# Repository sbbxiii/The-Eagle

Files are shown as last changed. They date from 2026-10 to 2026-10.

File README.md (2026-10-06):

# The Eagle — Custom STM32F405 Autonomous Flight Controller



[]()
[]()


**The Eagle** is a custom, 4-layer high-reliability avionics flight controller (FC) designed around the **STMicroelectronics STM32F405RGT6** microcontroller. Engineered for autonomous Unmanned Aerial Vehicles (UAVs) and high-performance robotics platforms, the board integrates high-bandwidth IMU telemetry, multi-stage power conditioning, blackbox high-rate logging, and deterministic motor signaling into a **40.0 × 40.0 mm** board footprint with a **34.0 × 34.0 mm** mounting hole pattern.

---

## 3D Isometric View

<p align="center">
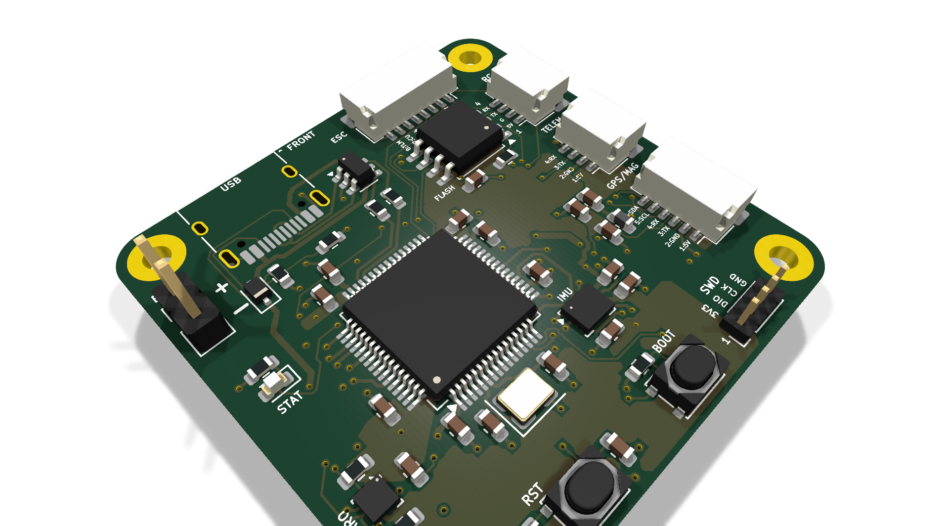
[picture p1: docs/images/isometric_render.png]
The Eagle Isometric Render
  
</p>

---

## Hardware Gallery & Subsystems

| Top View (Components & Silicon) | Bottom View (Power Stages & Silkscreen) |
| :---: | :---: |
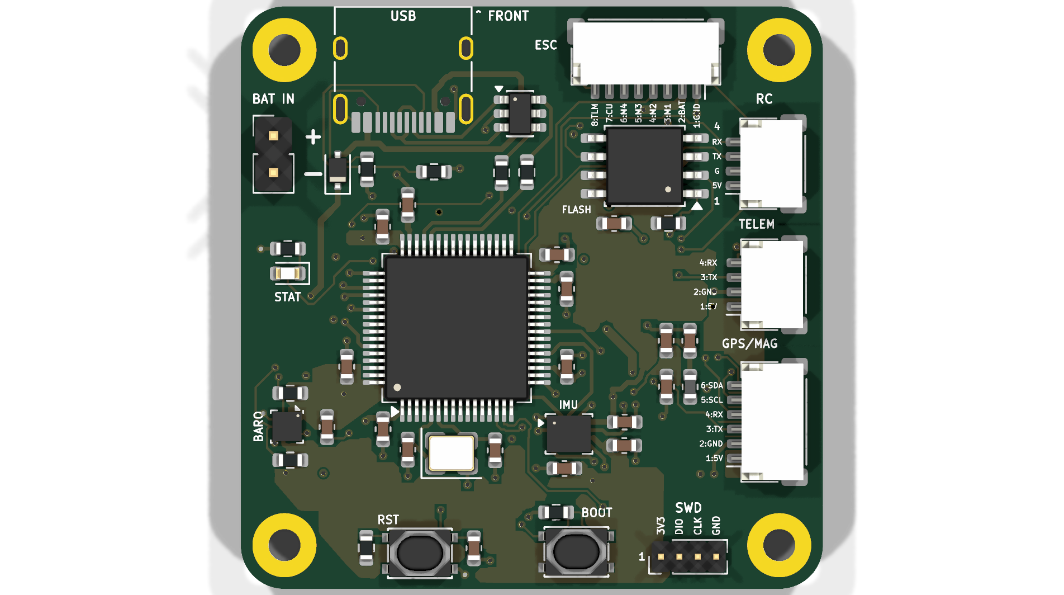
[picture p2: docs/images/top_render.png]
Top View
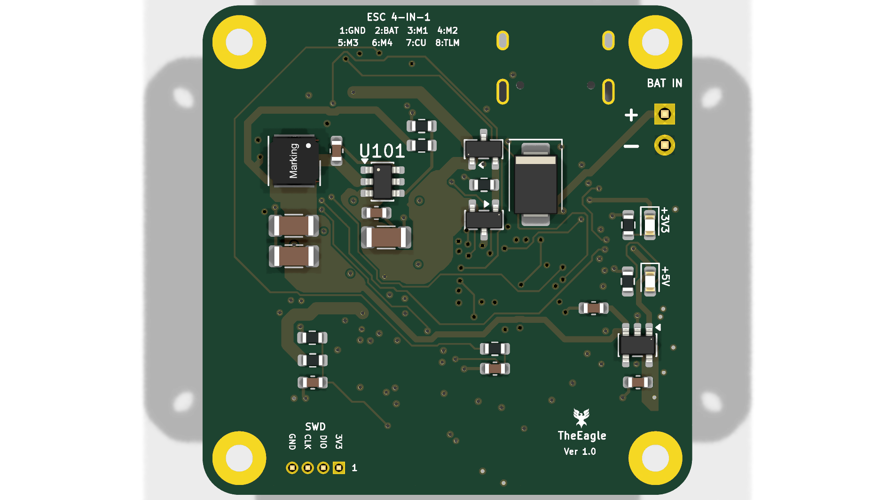
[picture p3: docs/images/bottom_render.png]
Bottom View
|  |  |
| *MCU, IMU, Baro, Flash, SWD, and I/O headers* | *Buck Regulator, LDO, TVS Diode, Reverse-Polarity FET, ESC pads* |

---

## Engineering Highlights & Key Specifications

### 1. Compute & Core Architecture
* **Primary MCU:** STM32F405RGT6 (ARM Cortex-M4 with single-precision FPU, 168 MHz core clock, 1 MB Flash, 192 KB SRAM).
* **Clocking:** External 8.000 MHz crystal oscillator feeding the internal PLL for zero-jitter core timing and USB 48 MHz generation.
* **Programming & Debug:** Onboard 4-pin SWD header (`3V3`, `SWDIO`, `SWCLK`, `GND`) for ST-Link / J-Link debugging and automated CI flashing.
* **Boot Management:** Hardware `BOOT` and `RST` tactile buttons supporting USB DFU system recovery.

### 2. Sensor Suite & Signal Integrity
* **Primary IMU:** **TDK InvenSense ICM-42688-P** 6-axis MEMS gyroscope/accelerometer on a dedicated high-speed **SPI1** bus (up to 20 MHz).
* **Interrupt Routing:** Dedicated hardware `EXTI` Data-Ready (`DRDY`) interrupt line tied directly to the MCU NVIC for deterministic 8 kHz loop timing.
* **Barometric Altimeter:** **Bosch Sensortec BMP390** precision pressure sensor on **I2C1** for sub-meter altitude hold.
* **Blackbox Storage:** **Winbond W25Q128JVSSIQ** (128 Mbit / 16 MB) SPI NOR Flash on **SPI3** for high-rate loop and telemetry logging.
* **Bus Isolation:** SPI and I2C signal traces are referenced directly to an unbroken Layer 2 Ground Plane to suppress crosstalk and high-frequency noise.

### 3. Power Distribution Network (PDN)
* **Battery Input:** 3S–6S LiPo input (9.0V to 26.0V nominal; rated up to 36V transient tolerance).
* **Transient Voltage Suppression (TVS):** Onboard **SMBJ28A** high-energy TVS clamp at the main battery junction to suppress motor inductive voltage spikes.
* **Reverse Polarity Protection:** P-channel MOSFET gate protection preventing accidental battery reverse-connection damage.
* **Synchronous Buck Converter:** Texas Instruments **LMR51430** step-down regulator delivering clean 5.0V @ 3.0A for receivers, telemetry, and peripheral rails.
* **Ultra-Low-Noise Sensor LDO:** Texas Instruments **TLV75733PDBV** (3.3V @ 1.0A) high-PSRR linear regulator exclusively isolating the analog sensors and MCU core.
* **Analog Telemetry:** Low-pass RC filtered 11:1 voltage divider (`VBAT_SENSE`) and ESC analog current input (`CURR_SENSE`).
* **USB Interface:** Micro-USB / USB-C pads protected by ST **USBLC6-2SC6** ultra-low capacitance bidirectional ESD suppressor.

---

## Silicon Registry & Pin Allocation Matrix

| Pin | Function | Peripheral Bus | Alternate Function | Purpose / Notes |
| :--- | :--- | :--- | :--- | :--- |
| **PA0** | `CURR_SENSE` | ADC1 | `ADC1_IN0` | Analog current sensing from ESC |
| **PA1** | `VBAT_SENSE` | ADC1 | `ADC1_IN1` | 11:1 voltage divider battery monitor |
| **PA4** | `IMU_CS` | GPIO | Output | Active-Low SPI Chip Select (ICM-42688-P) |
| **PA5** | `IMU_SCK` | SPI1 | `SPI1_SCK` | High-speed IMU clock (up to 20 MHz) |
| **PA6** | `IMU_MISO` | SPI1 | `SPI1_MISO` | IMU Master In / Slave Out |
| **PA7** | `IMU_MOSI` | SPI1 | `SPI1_MOSI` | IMU Master Out / Slave In |
| **PB0** | `MOTOR_1` | TIM3 | `TIM3_CH3` | Motor 1 output (DShot300/600 / PWM with DMA) |
| **PB1** | `MOTOR_2` | TIM3 | `TIM3_CH4` | Motor 2 output (DShot300/600 / PWM with DMA) |
| **PB4** | `MOTOR_3` | TIM3 | `TIM3_CH1` | Motor 3 output (DShot300/600 / PWM with DMA) |
| **PB5** | `MOTOR_4` | TIM3 | `TIM3_CH2` | Motor 4 output (DShot300/600 / PWM with DMA) |
| **PB6** | `I2C1_SCL` | I2C1 | `I2C1_SCL` | Barometer (BMP390) & External Magnetometer |
| **PB7** | `I2C1_SDA` | I2C1 | `I2C1_SDA` | Barometer (BMP390) & External Magnetometer |
| **PB10** | `UART3_TX` | USART3 | `USART3_TX` | ESC Telemetry / Auxiliary Serial |
| **PB11** | `UART3_RX` | USART3 | `USART3_RX` | ESC Telemetry / Auxiliary Serial |
| **PA9** | `UART1_TX` | USART1 | `USART1_TX` | High-speed Telemetry / Radio Control link |
| **PA10** | `UART1_RX` | USART1 | `USART1_RX` | High-speed Telemetry / Radio Control link |
| **PA2** | `UART2_TX` | USART2 | `USART2_TX` | GPS Receiver (UBX / NMEA protocol) |
| **PA3** | `UART2_RX` | USART2 | `USART2_RX` | GPS Receiver (UBX / NMEA protocol) |
| **PC10** | `FLASH_SCK` | SPI3 | `SPI3_SCK` | Blackbox Flash Clock |
| **PC11** | `FLASH_MISO`| SPI3 | `SPI3_MISO`| Blackbox Flash Data Out |
| **PC12** | `FLASH_MOSI`| SPI3 | `SPI3_MOSI`| Blackbox Flash Data In |
| **PD2** | `FLASH_CS` | GPIO | Output | Blackbox Flash Chip Select (W25Q128) |
| **PA11** | `USB_DM` | USB OTG FS | `OTG_FS_DM` | USB D- with ESD Clamping |
| **PA12** | `USB_DP` | USB OTG FS | `OTG_FS_DP` | USB D+ with ESD Clamping |
| **PA13** | `SWDIO` | SWD | `SWDIO` | Serial Wire Debug Data |
| **PA14** | `SWCLK` | SWD | `SWCLK` | Serial Wire Debug Clock |

---

## PCB Stackup & Fabrication Rules

* **Dimensions:** 40.00 mm × 40.00 mm outer footprint
* **Mounting Pattern:** 34.00 mm × 34.00 mm grid (M2 mounting pads)
* **Layer Count:** 4 Layers (Standard 1.6 mm FR-4 Stackup):
  * **Layer 1 (Top):** Component placement & High-Speed Signal routing
  * **Layer 2 (Inner 1):** Solid Ground Plane (GND) for low return-loop inductance
  * **Layer 3 (Inner 2):** Power Plane split (5.0V / 3.3V power distribution)
  * **Layer 4 (Bottom):** Power Switching Stages, ESC pads, and secondary signal traces
* **Minimum Trace / Space:** 0.15 mm / 0.15 mm (6 mil / 6 mil)
* **Minimum Drill:** 0.3 mm (via size: 0.6 mm outer diameter)
* **Design Rule Check (DRC):** **0 Errors, 0 Unconnected Nets**

---

## Manufacturing & Project Deliverables

All production assets are pre-generated and included in this repository:

* 📄 **Schematic (PDF):** [`schematic/TheEagle_Schematic.pdf`](schematic/TheEagle_Schematic.pdf)
* 📐 **Schematic (SVG):** [`schematic/TheEagle_Schematic.svg`](schematic/TheEagle_Schematic.svg)
* 📦 **Fabrication Gerbers & Drill (ZIP):** [`manufacturing/TheEagle_Gerbers_Rev1.zip`](manufacturing/TheEagle_Gerbers_Rev1.zip)
* 📋 **Bill of Materials (BOM CSV):** [`manufacturing/TheEagle_BOM.csv`](manufacturing/TheEagle_BOM.csv)
* 💻 **KiCad Source Files:** Located in [`hardware/`](hardware/)

---

## Firmware Compatibility

The hardware layout and pin allocation strictly adhere to the STM32 timer and peripheral mapping required by standard flight controller firmware:

1. **ArduPilot (ChibiOS):** Fully compatible via standard ChibiOS `hwdef.dat` board definition.
2. **Betaflight / INAV:** Compatible using STM32F405 target configuration with DShot DMA timer assignment.
3. **Custom Bare-Metal C++ / MATLAB Simulink:** Direct code generation via Embedded Coder / HAL drivers using the onboard SWD debug interface.

---

## How to Open in KiCad

1. Clone this repository:
   ```bash
   git clone https://github.com/sbbxiii/The-Eagle.git
   cd The-Eagle/hardware
   ```
2. Open `AeroHawk_FC.kicad_pro` using **KiCad 8.0 or newer** (tested on KiCad 10.0).
3. View schematics in `Eeschema` or board layout in `Pcbnew`.

---

## Author & License

Designed by **Osakwe**.  
Licensed under the [MIT License](LICENSE).

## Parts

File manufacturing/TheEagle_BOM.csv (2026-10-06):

Refs | Value | Footprint | Qty | DNP
C101 | 10uF 50V | Capacitor_SMD:C_1206_3216Metric | 1
C102 | 0.1uF 50V | Capacitor_SMD:C_0603_1608Metric | 1
C103 | 0.1uF 50V | Capacitor_SMD:C_0603_1608Metric | 1
C104 | 22uF 16V | Capacitor_SMD:C_1206_3216Metric | 1
C105 | 22uF 16V | Capacitor_SMD:C_1206_3216Metric | 1
C106 | 1uF 10V | Capacitor_SMD:C_0603_1608Metric | 1
C107 | 2.2uF 10V | Capacitor_SMD:C_0603_1608Metric | 1
C108 | 100nF | Capacitor_SMD:C_0603_1608Metric | 1
C109 | 100nF | Capacitor_SMD:C_0603_1608Metric | 1
C201 | 100nF | Capacitor_SMD:C_0603_1608Metric | 1
C202 | 100nF | Capacitor_SMD:C_0603_1608Metric | 1
C203 | 100nF | Capacitor_SMD:C_0603_1608Metric | 1
C204 | 100nF | Capacitor_SMD:C_0603_1608Metric | 1
C205 | 4.7uF 10V | Capacitor_SMD:C_0603_1608Metric | 1
C206 | 1uF 10V | Capacitor_SMD:C_0603_1608Metric | 1
C207 | 100nF | Capacitor_SMD:C_0603_1608Metric | 1
C208 | 2.2uF 16V | Capacitor_SMD:C_0603_1608Metric | 1
C209 | 2.2uF 16V | Capacitor_SMD:C_0603_1608Metric | 1
C210 | 33pF C0G | Capacitor_SMD:C_0603_1608Metric | 1
C211 | 33pF C0G | Capacitor_SMD:C_0603_1608Metric | 1
C212 | 100nF | Capacitor_SMD:C_0603_1608Metric | 1
C213 | 1uF 10V | Capacitor_SMD:C_0603_1608Metric | 1
C301 | 100nF | Capacitor_SMD:C_0603_1608Metric | 1
C302 | 1uF 10V | Capacitor_SMD:C_0603_1608Metric | 1
C303 | 100nF | Capacitor_SMD:C_0603_1608Metric | 1
C304 | 100nF | Capacitor_SMD:C_0603_1608Metric | 1
C305 | 100nF | Capacitor_SMD:C_0603_1608Metric | 1
D101 | SMBJ28CA | Diode_SMD:D_SMB | 1
D102 | BZX84C12 | Package_TO_SOT_SMD:SOT-23 | 1
D103 | Green LED | LED_SMD:LED_0603_1608Metric | 1
D104 | Blue LED | LED_SMD:LED_0603_1608Metric | 1
D401 | PMEG3020EJ | Diode_SMD:D_SOD-323F | 1
D403 | Red LED | LED_SMD:LED_0603_1608Metric | 1
FB201 | Ferrite Bead (600Ω) | Inductor_SMD:L_0603_1608Metric | 1
J101 | BAT_IN | Connector_PinHeader_2.54mm:PinHeader_1x02_P2.54mm_Vertical | 1
J201 | SWD_DEBUG | Connector_PinHeader_1.27mm:PinHeader_1x04_P1.27mm_Vertical | 1
J401 | USB_C | Connector_USB:USB_C_Receptacle_HRO_TYPE-C-31-M-12 | 1
J402 | ESC_4IN1 | Connector_JST:JST_SH_SM08B-SRSS-TB_1x08-1MP_P1.00mm_Horizontal | 1
J403 | GPS_MAG | Connector_JST:JST_SH_SM06B-SRSS-TB_1x06-1MP_P1.00mm_Horizontal | 1
J404 | TELEM_GCS | Connector_JST:JST_SH_SM04B-SRSS-TB_1x04-1MP_P1.00mm_Horizontal | 1
J405 | RC_RECEIVER | Connector_JST:JST_SH_SM04B-SRSS-TB_1x04-1MP_P1.00mm_Horizontal | 1
L101 | 10uH | Inductor_SMD_Wurth:L_Wurth_WE-LQSH-4020 | 1
Q101 | Si2319CDS | Package_TO_SOT_SMD:SOT-23 | 1
R101 | 100k | Resistor_SMD:R_0603_1608Metric | 1
R102 | 100k 1% | Resistor_SMD:R_0603_1608Metric | 1
R103 | 13.3k 1% | Resistor_SMD:R_0603_1608Metric | 1
R104 | 10k 0.1% | Resistor_SMD:R_0603_1608Metric | 1
R105 | 1k 0.1% | Resistor_SMD:R_0603_1608Metric | 1
R106 | 1k | Resistor_SMD:R_0603_1608Metric | 1
R107 | 1k | Resistor_SMD:R_0603_1608Metric | 1
R108 | 470R | Resistor_SMD:R_0603_1608Metric | 1
R202 | 10k | Resistor_SMD:R_0603_1608Metric | 1
R203 | 10k | Resistor_SMD:R_0603_1608Metric | 1
R301 | 2.2k | Resistor_SMD:R_0603_1608Metric | 1
R302 | 2.2k | Resistor_SMD:R_0603_1608Metric | 1
R303 | 10k | Resistor_SMD:R_0603_1608Metric | 1
R401 | 5.1k 1% | Resistor_SMD:R_0603_1608Metric | 1
R402 | 5.1k 1% | Resistor_SMD:R_0603_1608Metric | 1
R403 | 22R | Resistor_SMD:R_0603_1608Metric | 1
R404 | 22R | Resistor_SMD:R_0603_1608Metric | 1
R407 | 1k | Resistor_SMD:R_0603_1608Metric | 1
SW201 | Pushbutton (NRST) | Button_Switch_SMD:SW_Push_SPST_NO_PTS810 | 1
SW202 | Pushbutton (BOOT0) | Button_Switch_SMD:SW_Push_SPST_NO_PTS810 | 1
U101 | LMR51430 | Package_TO_SOT_SMD:SOT-23-6 | 1
U102 | TLV75733PDBV | Package_TO_SOT_SMD:SOT-23-5 | 1
U201 | STM32F405RGT6 | Package_QFP:LQFP-64_10x10mm_P0.5mm | 1
U301 | ICM-42688-P | Package_LGA:InvenSense_LGA-14_2.5x3mm_P0.5mm | 1
U302 | BMP390 | Package_LGA:Bosch_LGA-10_2x2mm_P0.5mm | 1
U303 | W25Q128JVSSIQ | Package_SO:SOIC-8_5.23x5.23mm_P1.27mm | 1
U402 | USBLC6-2SC6 | Package_TO_SOT_SMD:SOT-23-6 | 1
Y201 | 8.000MHz | Crystal:Crystal_SMD_3225-4Pin_3.2x2.5mm | 1

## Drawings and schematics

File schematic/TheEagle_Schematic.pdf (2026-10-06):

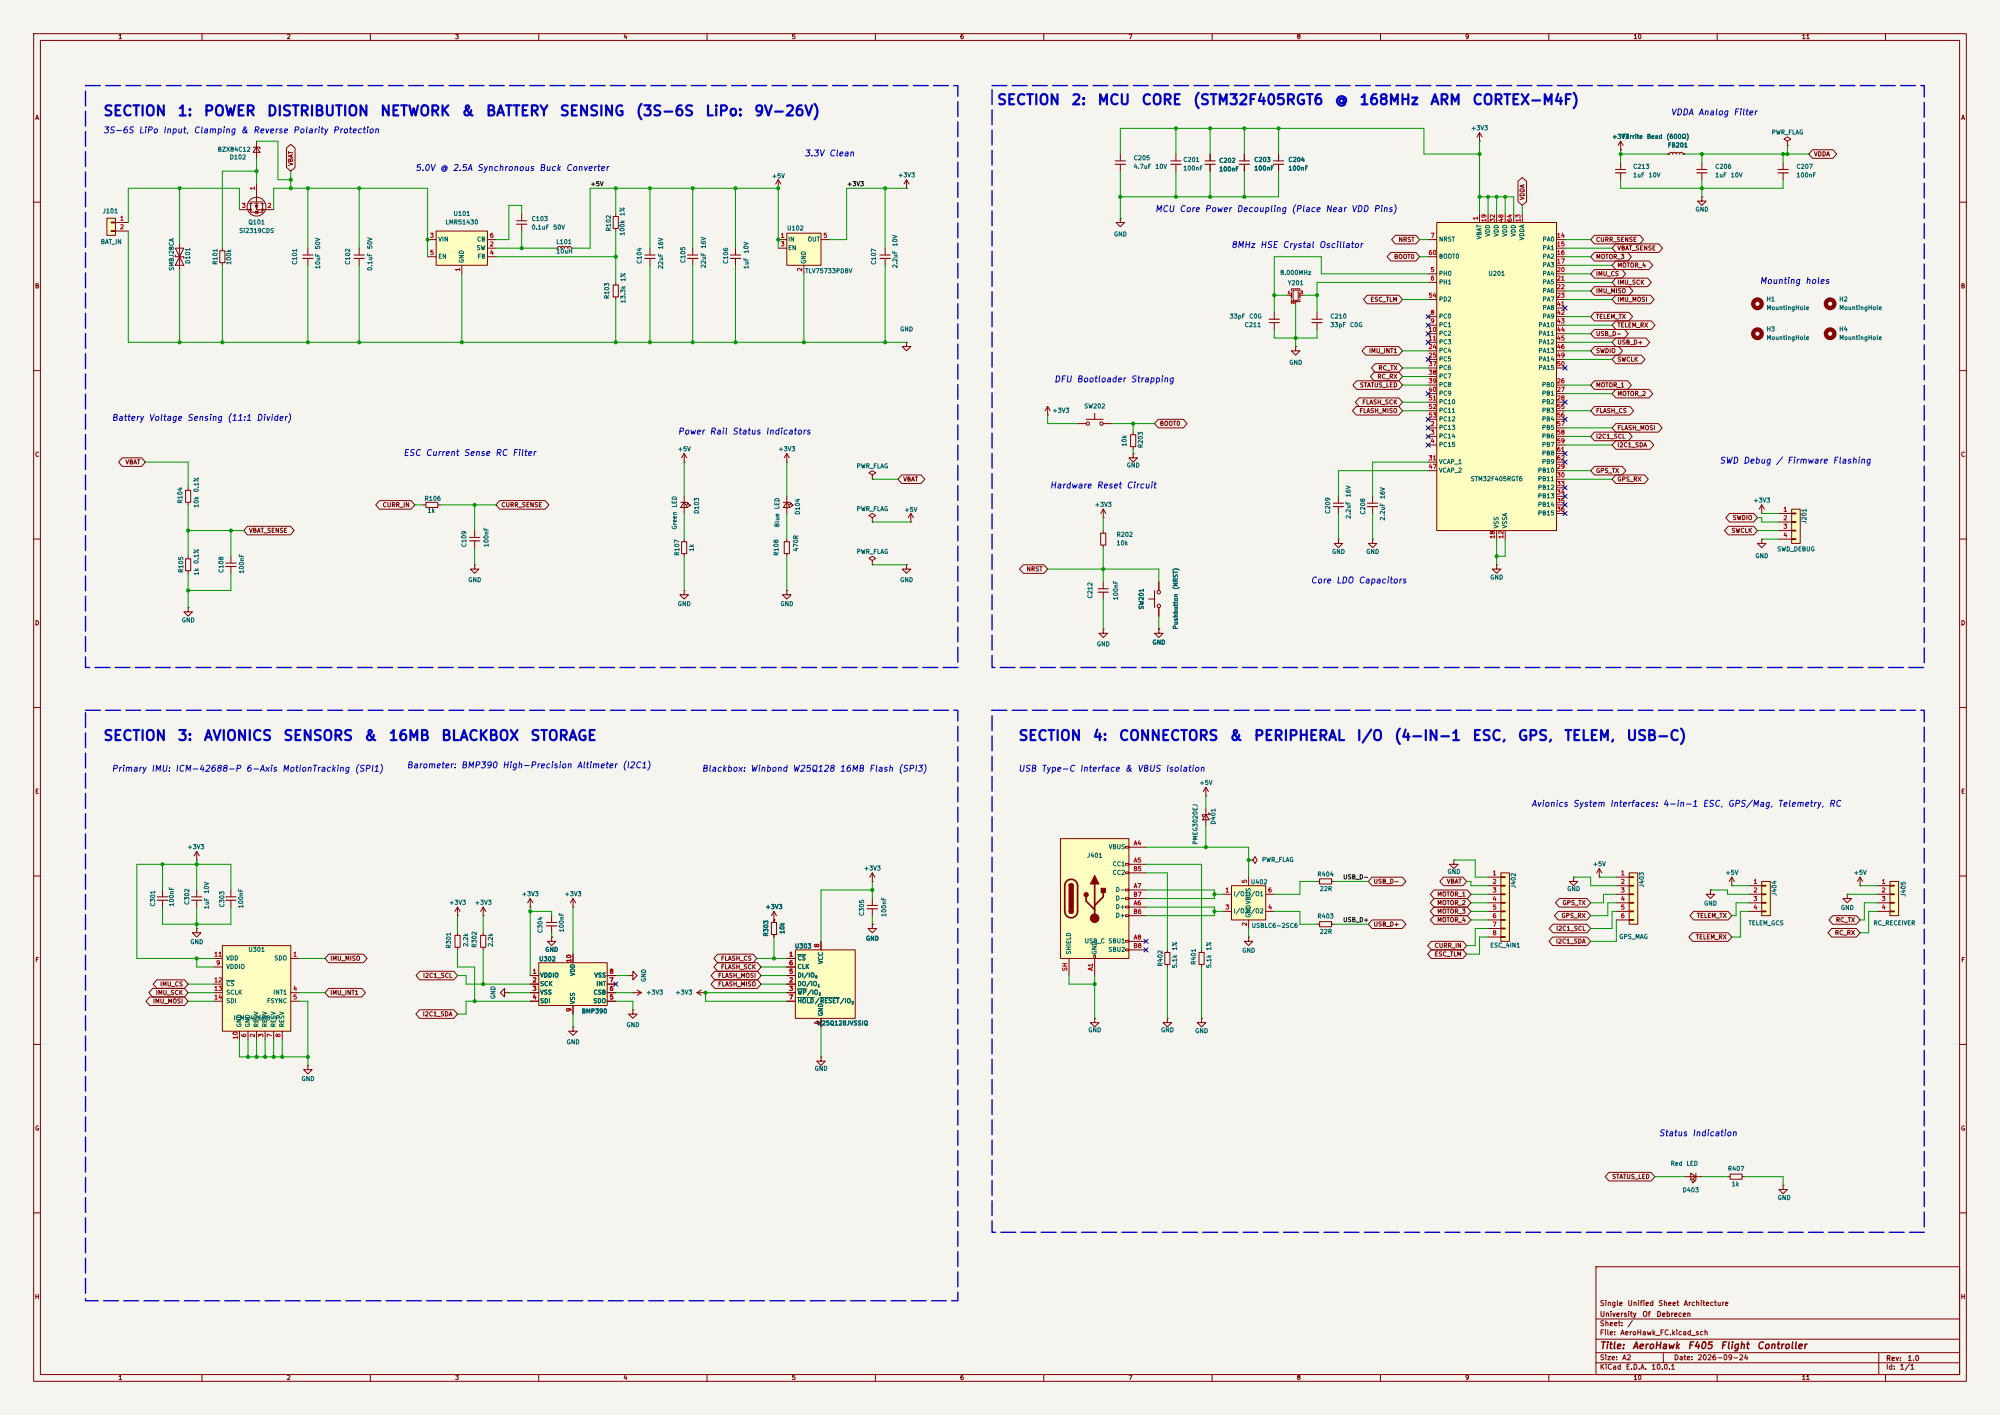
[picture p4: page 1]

SECTION 2: MCU CORE (STM32F405RGT6 @ 168MHz ARM CORTEX-M4F)

SECTION 1: POWER DISTRIBUTION NETWORK & BATTERY SENSING (3S-6S LiPo: 9V-26V)

3S-6S LiPo Input, Clamping & Reverse Polarity Protection

MCU Core Power Decoupling (Place Near VDD Pins)

Battery Voltage Sensing (11:1 Divider)

Power Rail Status Indicators

ESC Current Sense RC Filter

SWD Debug / Firmware Flashing

SECTION 3: AVIONICS SENSORS & 16MB BLACKBOX STORAGE

SECTION 4: CONNECTORS & PERIPHERAL I/O (4-IN-1 ESC, GPS, TELEM, USB-C)

Primary IMU: ICM-42688-P 6-Axis MotionTracking (SPI1)

Avionics System Interfaces: 4-in-1 ESC, GPS/Mag, Telemetry, RC

4 DI/IO0 5 CLK 6 HOLD/RESET/IO3 7 VCC U303 8 GND W25Q128JVSSIQ GND

4 DI/IO0 5 CLK 6 HOLD/RESET/IO3 7 VCC

Single Unified Sheet Architecture
University Of Debrecen
Sheet: /
File: AeroHawk_FC.kicad_sch
Title: AeroHawk F405 Flight Controller

Size: A2 | Rev: 1.0
KiCad E.D.A. 10.0.1 | Id: 1/1

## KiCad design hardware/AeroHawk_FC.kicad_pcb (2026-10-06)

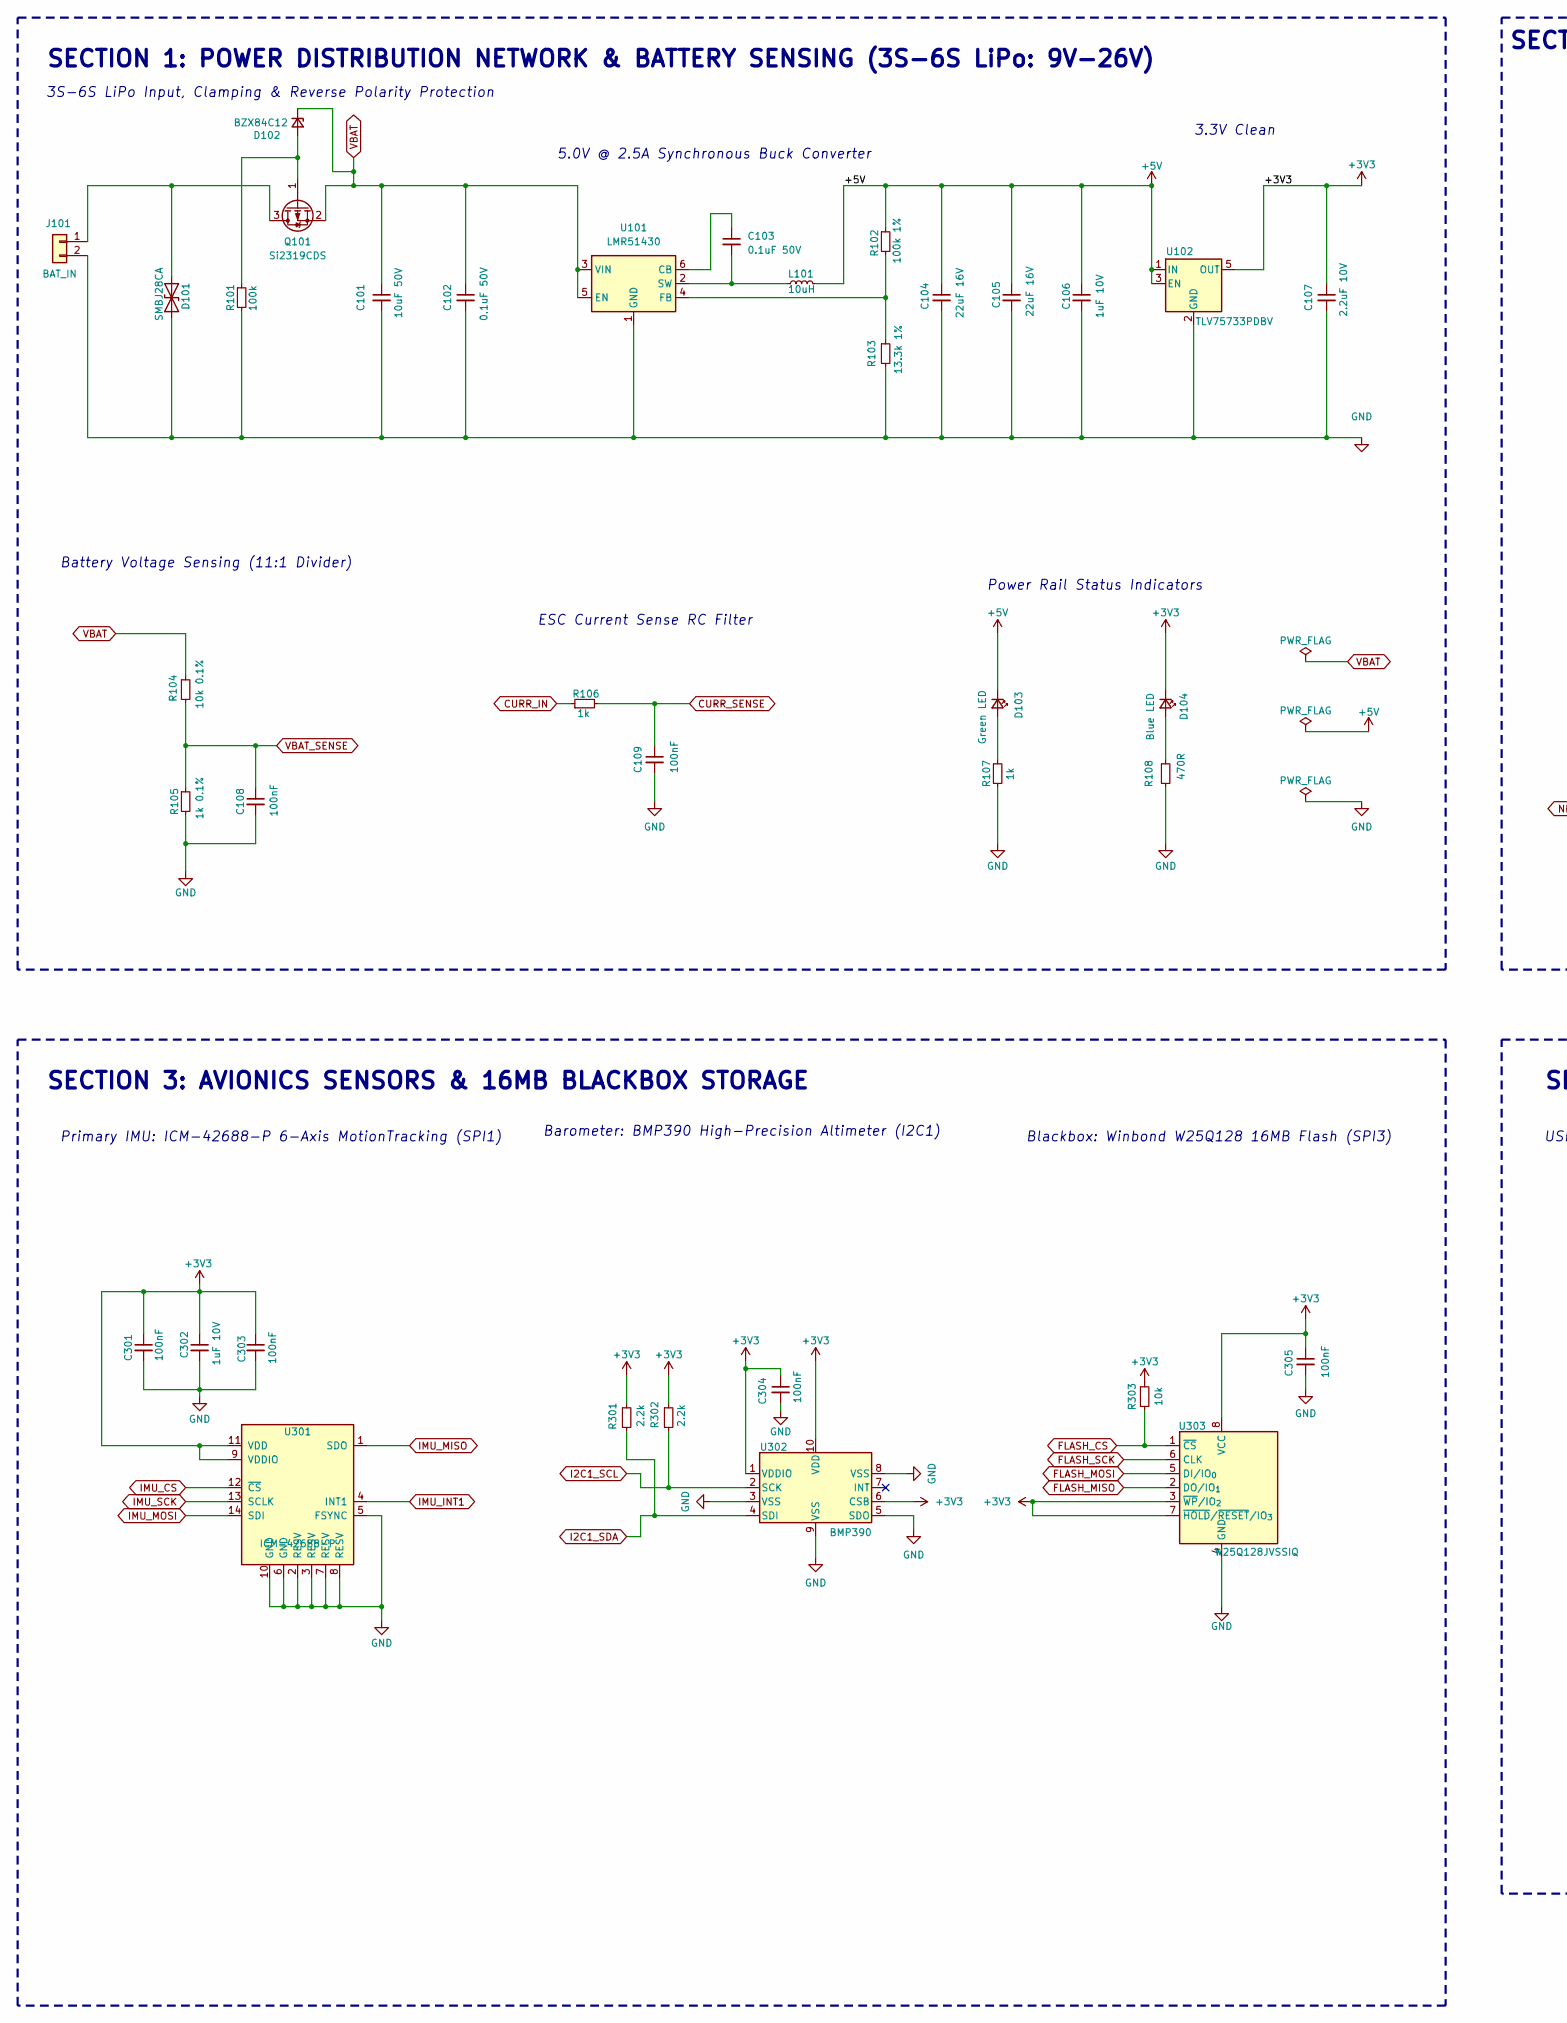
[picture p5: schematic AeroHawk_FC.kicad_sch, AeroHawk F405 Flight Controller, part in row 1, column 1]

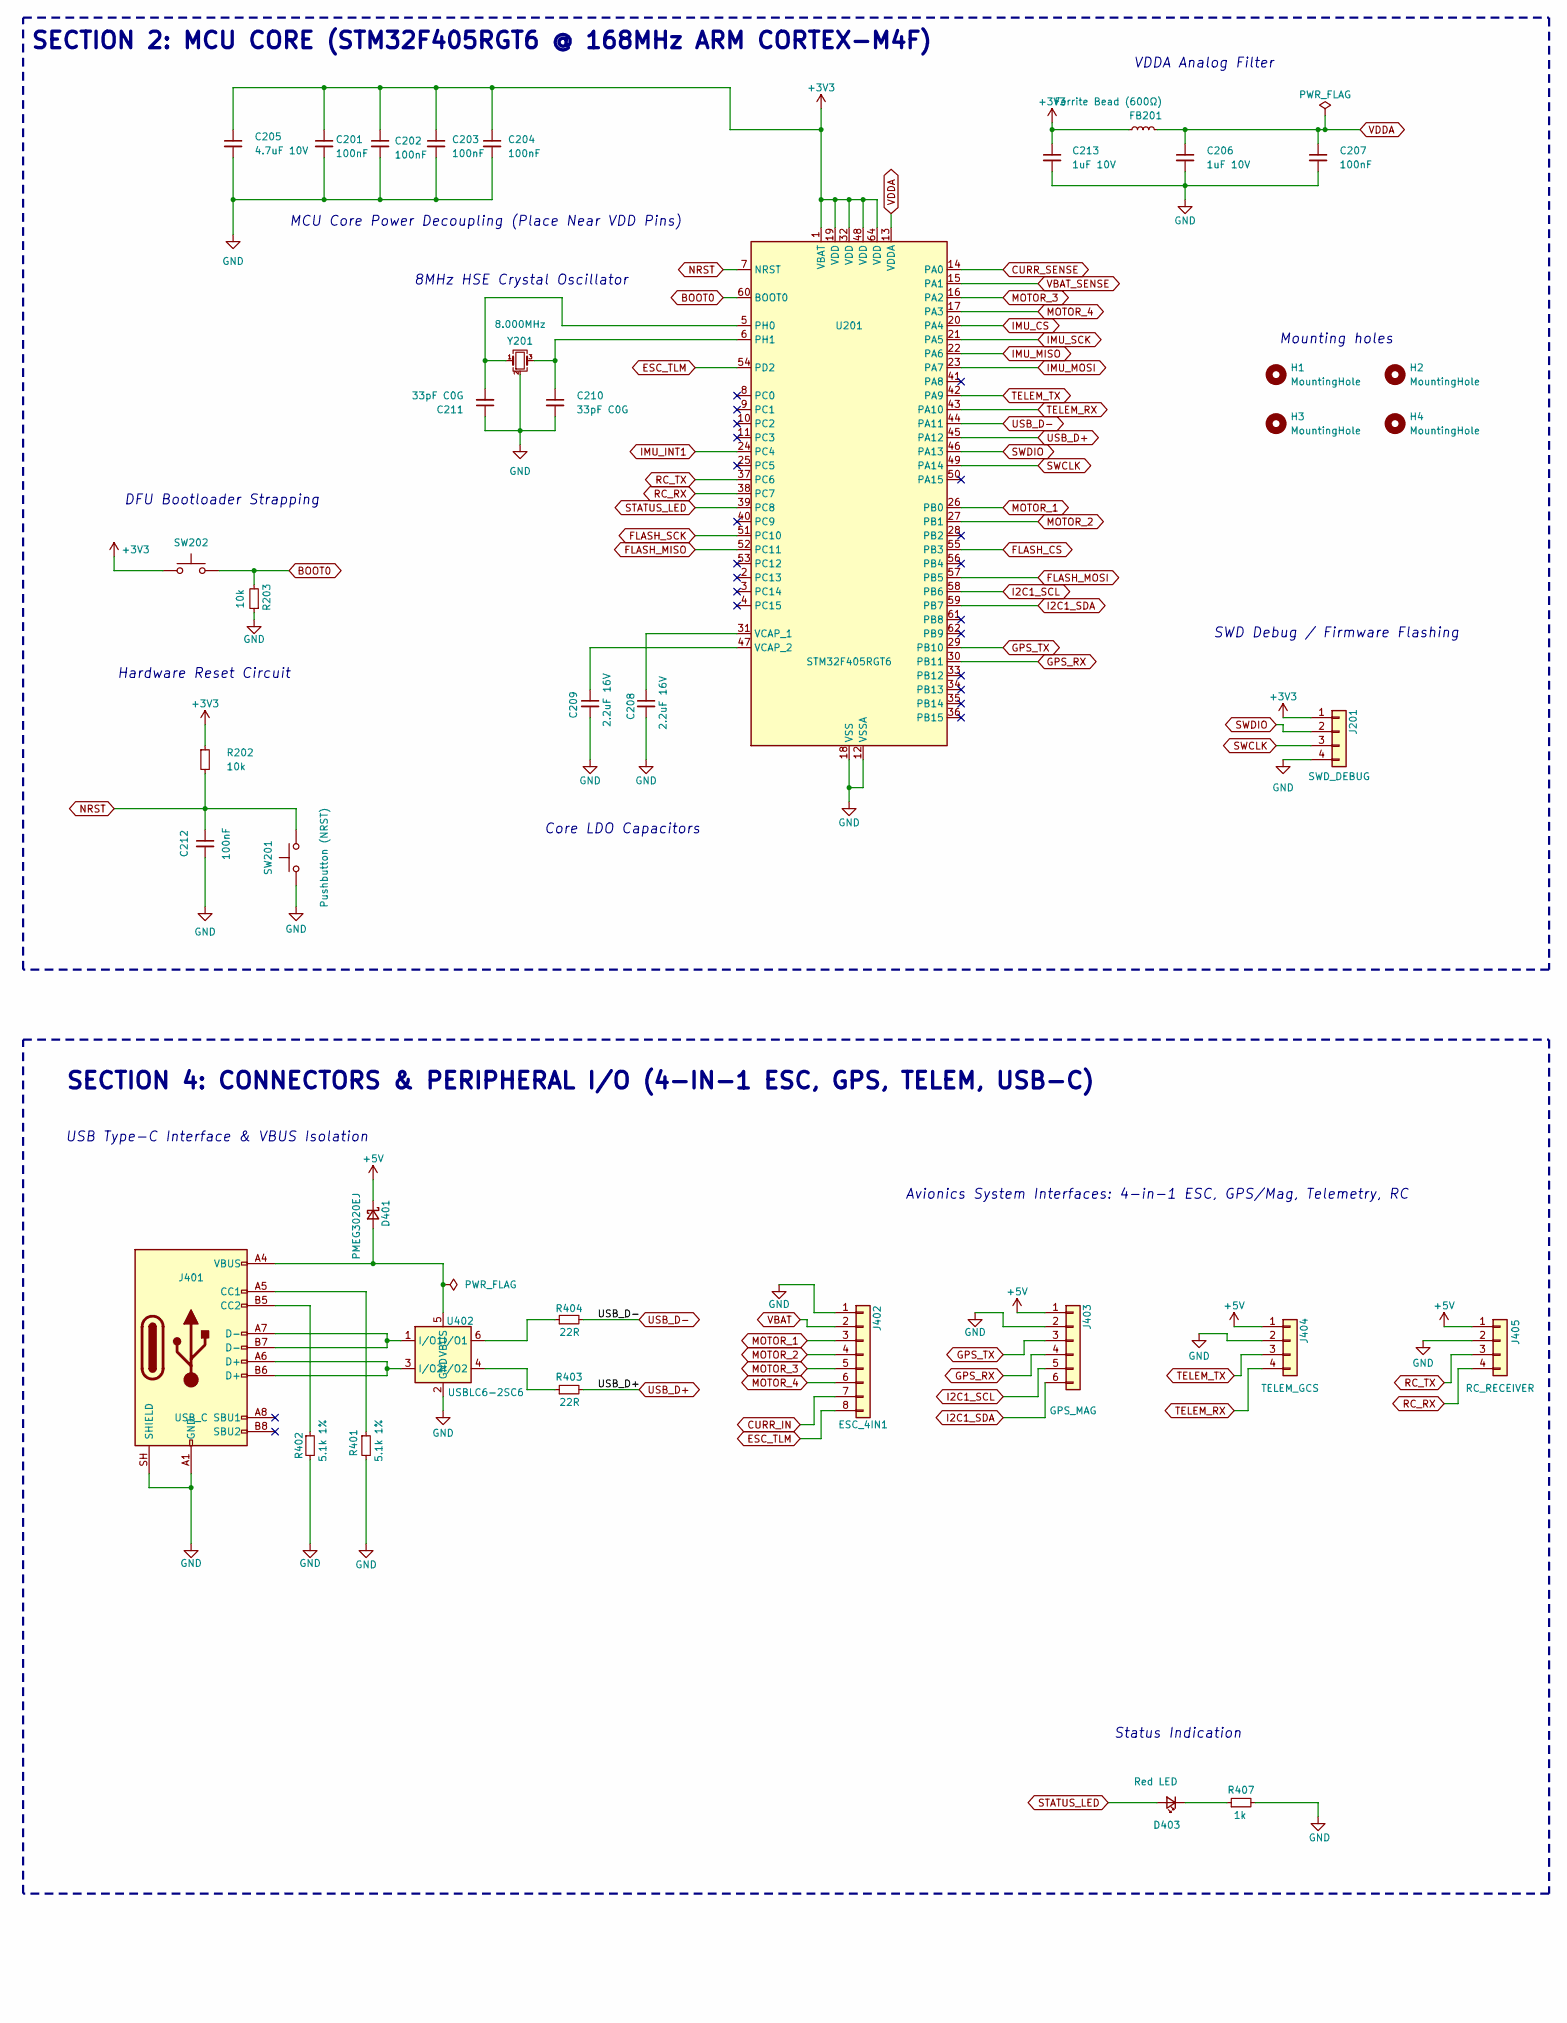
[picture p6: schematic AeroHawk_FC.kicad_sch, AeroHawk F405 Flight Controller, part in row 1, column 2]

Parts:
C101: 10uF 50V; C_1206_3216Metric; MPN CL31B106KBHNNNE
C102, C103: 0.1uF 50V; C_0603_1608Metric; MPN CC0603KRX7R9BB104
C104, C105: 22uF 16V; C_1206_3216Metric; MPN CL21A226MPCLRNC
C106, C206, C213, C302: 1uF 10V; C_0603_1608Metric; MPN CC0603KRX7R7BB105
C107: 2.2uF 10V; C_0603_1608Metric; MPN CC0603KRX7R7BB225
C108, C109, C201, C202, C203, C204, C207, C212, C301, C303, C304, C305: 100nF; C_0603_1608Metric; MPN CC0603KRX7R9BB104
C205: 4.7uF 10V; C_0603_1608Metric; MPN CC0603KRX7R9BB104
C208, C209: 2.2uF 16V; C_0603_1608Metric; MPN CC0603KRX7R7BB225
C210, C211: 33pF C0G; C_0603_1608Metric; MPN CC0603JRNPO9BN180
D101: SMBJ28CA; D_SMB; MPN SMBJ28CA
D102: BZX84C12; SOT-23; MPN BZX84C12
D103: Green LED; LED_0603_1608Metric; MPN 19-217/GHC-YR1S2/3T
D104: Blue LED; LED_0603_1608Metric; MPN 19-217/BHC-AP1Q2/3T
D401: PMEG3020EJ; D_SOD-323F; MPN PMEG3020EJ
D403: Red LED; LED_0603_1608Metric; MPN 19-217/R6C-AL1M2VY/3T
FB201: Ferrite Bead (600Ω); L_0603_1608Metric; MPN BLM18PG121SN1D
H1, H2, H3, H4: MountingHole; MountingHole_2.2mm_M2_Pad
J101: BAT_IN; PinHeader_1x02_P2.54mm_Vertical; MPN 22-23-2021
J201: SWD_DEBUG; PinHeader_1x04_P1.27mm_Vertical; MPN M50-3530442
J401: USB_C; USB_C_Receptacle_HRO_TYPE-C-31-M-12; MPN TYPE-C-31-M-12
J402: ESC_4IN1; JST_SH_SM08B-SRSS-TB_1x08-1MP_P1.00mm_Horizontal; MPN SM08B-SRSS-TB
J403: GPS_MAG; JST_SH_SM06B-SRSS-TB_1x06-1MP_P1.00mm_Horizontal; MPN SM06B-SRSS-TB
J404: TELEM_GCS; JST_SH_SM04B-SRSS-TB_1x04-1MP_P1.00mm_Horizontal; MPN SM04B-SRSS-TB
J405: RC_RECEIVER; JST_SH_SM04B-SRSS-TB_1x04-1MP_P1.00mm_Horizontal; MPN SM04B-SRSS-TB
L101: 10uH; L_Wurth_WE-LQSH-4020; MPN 74405042100
Q101: Si2319CDS; SOT-23; MPN Si2319CDS-T1-GE3
R101: 100k; R_0603_1608Metric; MPN RC0603FR-07100KL
R102: 100k 1%; R_0603_1608Metric; MPN RC0603FR-07100KL
R103: 13.3k 1%; R_0603_1608Metric; MPN RC0603FR-0713K3L
R104: 10k 0.1%; R_0603_1608Metric; MPN RT0603BRD0710KL
R105: 1k 0.1%; R_0603_1608Metric; MPN RT0603BRD071KL
R106, R107, R407: 1k; R_0603_1608Metric; MPN RC0603FR-071KL
R108: 470R; R_0603_1608Metric; MPN RC0603FR-071KL
R202, R203, R303: 10k; R_0603_1608Metric; MPN RC0603FR-0710KL
R301, R302: 2.2k; R_0603_1608Metric; MPN RC0603FR-072K2L
R401, R402: 5.1k 1%; R_0603_1608Metric; MPN RC0603FR-075K1L
R403, R404: 22R; R_0603_1608Metric; MPN RC0603FR-0722RL
SW201: Pushbutton (NRST); SW_Push_SPST_NO_PTS810; MPN PTS810SJM250SMTRLFS
SW202: Pushbutton (BOOT0); SW_Push_SPST_NO_PTS810; MPN PTS810SJM250SMTRLFS
U101: LMR51430; SOT-23-6; MPN LMR51430XDDCR
U102: TLV75733PDBV; SOT-23-5; MPN TLV75733PDBVR
U201: STM32F405RGT6; LQFP-64_10x10mm_P0.5mm; MPN STM32F405RGT6
U301: ICM-42688-P; InvenSense_LGA-14_2.5x3mm_P0.5mm; MPN ICM-42688-P
U302: BMP390; Bosch_LGA-10_2x2mm_P0.5mm; MPN BMP390
U303: W25Q128JVSSIQ; SOIC-8_5.23x5.23mm_P1.27mm; MPN W25Q128JVSIQ
U402: USBLC6-2SC6; SOT-23-6; MPN USBLC6-2SC6
Y201: 8.000MHz; Crystal_SMD_3225-4Pin_3.2x2.5mm; MPN X32258MSB4SI

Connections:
+3V3: C107.1, C201.1, C202.1, C203.1, C204.1, C205.1, C213.1, C301.1, C302.1, C303.1, C304.1, C305.1, D104.1 (K), FB201.1, J201.1, R202.1, R301.1, R302.1, R303.1, SW202.1, U102.5 (OUT), U201.1 (VBAT), U201.19 (VDD), U201.32 (VDD), U201.48 (VDD), U201.64 (VDD), U301.9 (VDDIO), U301.11 (VDD), U302.1 (VDDIO), U302.6 (CSB), U302.10 (VDD), U303.3 (~WP/IO_{2}), U303.7 (~HOLD/~RESET/IO_{3}), U303.8 (VCC)
BOOT0: R203.2, SW202.2, U201.60 (BOOT0)
CURR_IN: J402.7, R106.1
CURR_SENSE: C109.1, R106.2, U201.14 (PA0)
ESC_TLM: J402.8, U201.54 (PD2)
FLASH_CS: R303.2, U201.55 (PB3), U303.1 (~CS)
FLASH_MISO: U201.52 (PC11), U303.2 (DO/IO_{1})
FLASH_MOSI: U201.57 (PB5), U303.5 (DI/IO_{0})
FLASH_SCK: U201.51 (PC10), U303.6 (CLK)
GPS_RX: J403.4, U201.30 (PB11)
GPS_TX: J403.3, U201.29 (PB10)
I2C1_SCL: J403.5, R302.2, U201.58 (PB6), U302.2 (SCK)
I2C1_SDA: J403.6, R301.2, U201.59 (PB7), U302.4 (SDI)
IMU_CS: U201.20 (PA4), U301.12 (~CS)
IMU_INT1: U201.24 (PC4), U301.4 (INT1)
IMU_MISO: U201.22 (PA6), U301.1 (SDO)
IMU_MOSI: U201.23 (PA7), U301.14 (SDI)
IMU_SCK: U201.21 (PA5), U301.13 (SCLK)
MOTOR_1: J402.3, U201.26 (PB0)
MOTOR_2: J402.4, U201.27 (PB1)
MOTOR_3: J402.5, U201.16 (PA2)
MOTOR_4: J402.6, U201.17 (PA3)
NRST: C212.1, R202.2, SW201.2, U201.7 (NRST)
unnamed: D101.2 (A2), J101.1, Q101.3 (D)
unnamed: D102.2 (A), Q101.1 (G), R101.1
unnamed: D103.2 (A), R107.1
unnamed: D104.2 (A), R108.1
unnamed: D403.1 (K), R407.1
unnamed: J401.A5 (CC1), R401.1
unnamed: J401.B5 (CC2), R402.1
unnamed: J401.A6 (D+), J401.B6 (D+), U402.3 (I/O2)
unnamed: J401.A7 (D-), J401.B7 (D-), U402.1 (I/O1)
unnamed: R403.1, U402.4 (I/O2)
unnamed: R404.1, U402.6 (I/O1)
unnamed: C103.1, U101.6 (CB)
unnamed: R102.2, R103.1, U101.4 (FB)
unnamed: C103.2, L101.1, U101.2 (SW)
unnamed: C211.2, U201.5 (PH0), Y201.1
unnamed: C210.1, U201.6 (PH1), Y201.3
unnamed: C208.1, U201.31 (VCAP_1)
unnamed: C209.1, U201.47 (VCAP_2)
RC_RX: J405.4, U201.38 (PC7)
RC_TX: J405.3, U201.37 (PC6)
STATUS_LED: D403.2 (A), U201.39 (PC8)
SWCLK: J201.3, U201.49 (PA14)
SWDIO: J201.2, U201.46 (PA13)
TELEM_RX: J404.4, U201.43 (PA10)
TELEM_TX: J404.3, U201.42 (PA9)
USB_D+: R403.2, U201.45 (PA12)
USB_D-: R404.2, U201.44 (PA11)
VBAT_SENSE: C108.1, R104.2, R105.1, U201.15 (PA1)

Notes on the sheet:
Blackbox: Winbond W25Q128 16MB Flash (SPI3)
Battery Voltage Sensing (11:1 Divider)
8MHz HSE Crystal Oscillator
SWD Debug / Firmware Flashing
Barometer: BMP390 High-Precision Altimeter (I2C1)
MCU Core Power Decoupling (Place Near VDD Pins)
SECTION 3: AVIONICS SENSORS & 16MB BLACKBOX STORAGE
USB Type-C Interface & VBUS Isolation
Power Rail Status Indicators
5.0V @ 2.5A Synchronous Buck Converter
Core LDO Capacitors
SECTION 2: MCU CORE (STM32F405RGT6 @ 168MHz ARM CORTEX-M4F)
3S-6S LiPo Input, Clamping & Reverse Polarity Protection
Mounting holes
Avionics System Interfaces: 4-in-1 ESC, GPS/Mag, Telemetry, RC
SECTION 1: POWER DISTRIBUTION NETWORK & BATTERY SENSING (3S-6S LiPo: 9V-26V)
Hardware Reset Circuit
3.3V Clean
SECTION 4: CONNECTORS & PERIPHERAL I/O (4-IN-1 ESC, GPS, TELEM, USB-C)
ESC Current Sense RC Filter
VDDA Analog Filter
DFU Bootloader Strapping
Primary IMU: ICM-42688-P 6-Axis MotionTracking (SPI1)
Status Indication

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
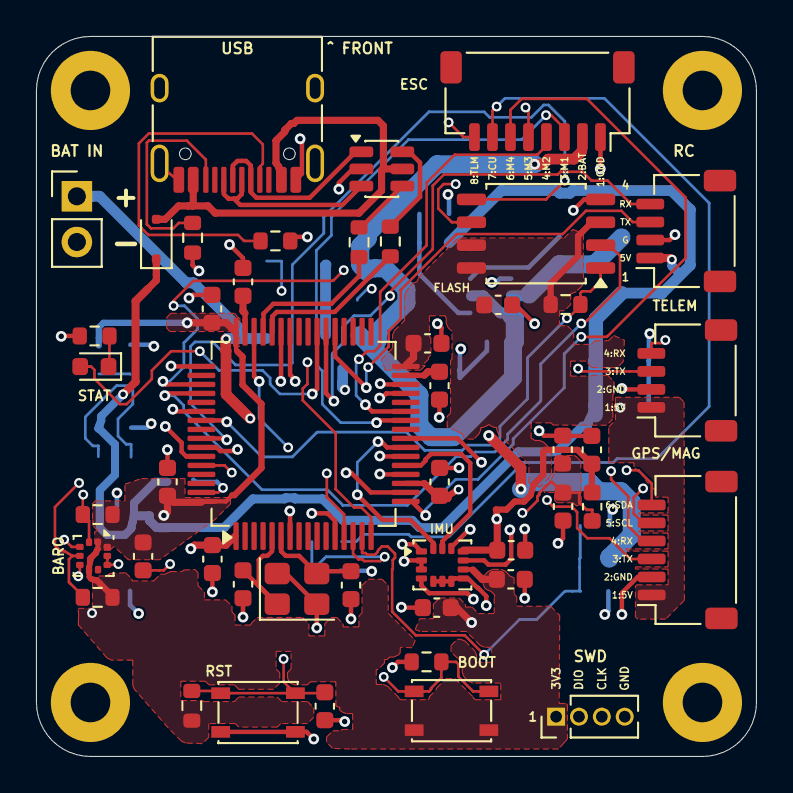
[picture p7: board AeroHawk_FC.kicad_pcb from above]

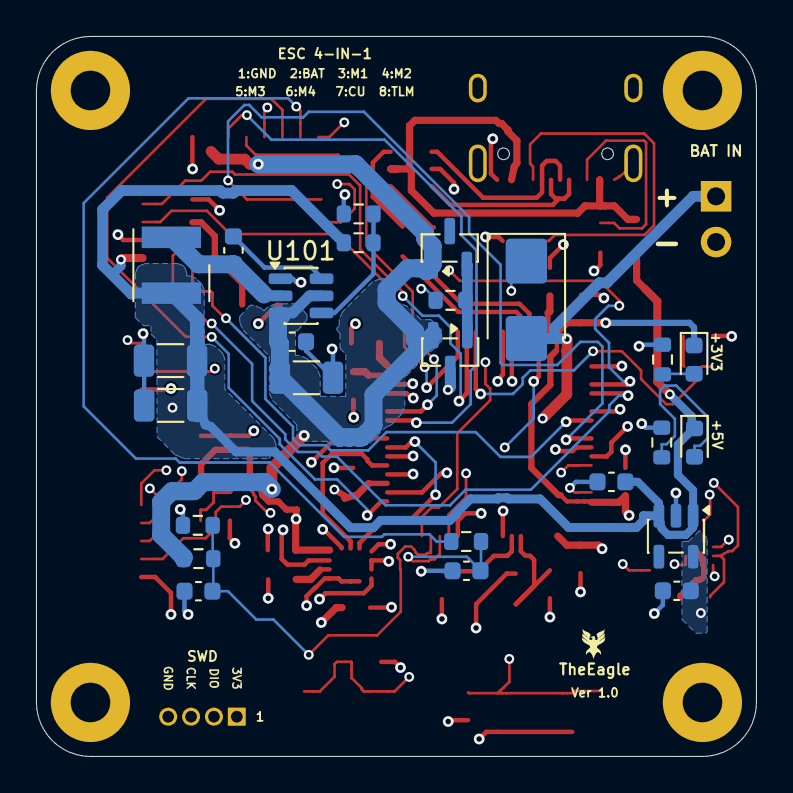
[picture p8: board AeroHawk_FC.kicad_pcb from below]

Board: 4 copper layers, 40.0 x 40.0 mm, 75 parts (25 on the bottom side), 56 nets.

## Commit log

2026-10-06 Initial commit: The Eagle STM32F405 Flight Controller v1.0
    [AeroHawk_FC.kicad_pcb, AeroHawk_FC.kicad_sch, TheEagle_BOM.csv]
2026-10-06 fix(docs): correct board dimensions to 40.0 x 40.0 mm
2026-10-06 fix(docs): correct mounting pattern to 34.0 x 34.0 mm grid

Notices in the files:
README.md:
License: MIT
